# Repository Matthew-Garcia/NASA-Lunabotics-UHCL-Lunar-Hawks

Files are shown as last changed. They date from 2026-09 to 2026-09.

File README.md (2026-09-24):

> **New simulation review branch:** [Full rover CAD, Gazebo/RViz launch and KiCad Rev C](docs/SIMULATION_REVIEW.md). Reference-derived geometry; runtime and electrical review remain pending.

<p align="center">UHCL Lunar Hawks team logo</p>

# NASA Lunabotics · UHCL Lunar Hawks

### Proof-of-concept lunar excavation rover
Embedded systems · ROS 2 · micro-ROS · OpenCV · LiDAR · Gazebo · Hardware integration

A University of Houston–Clear Lake student and research rover project for lunar-regolith excavation, collection, transportation, and disposal.

This repository brings together the Lunar Hawks rover's ESP32 firmware, NVIDIA Jetson ROS 2 software, micro-ROS communication, mechanical models, electrical documentation, Gazebo simulation assets, and ongoing autonomous-navigation development.

**Status: prototype / research.** Physical rover subsystems have been demonstrated, while the newly added autonomous mission software and simulation environment remain development implementations requiring integration and validation on the physical rover.

This is a team-member-maintained academic/research repository and is **not a NASA-owned or NASA-endorsed software release**.

[ROS 2](ros2_ws/README.md) ·
[micro-ROS](firmware/micro_ros/README.md) ·
[MicroPython](firmware/micropython/README.md) ·
[Autonomy](ros2_ws/src/lunabotics_autonomy/) ·
[Gazebo Simulation](simulation/) ·
[CAD](cad/) ·
[Control PCB](hardware/rover_control_pcb/README.md) ·
[Research](docs/publication/README.md) ·
[Testing](docs/testing/README.md)

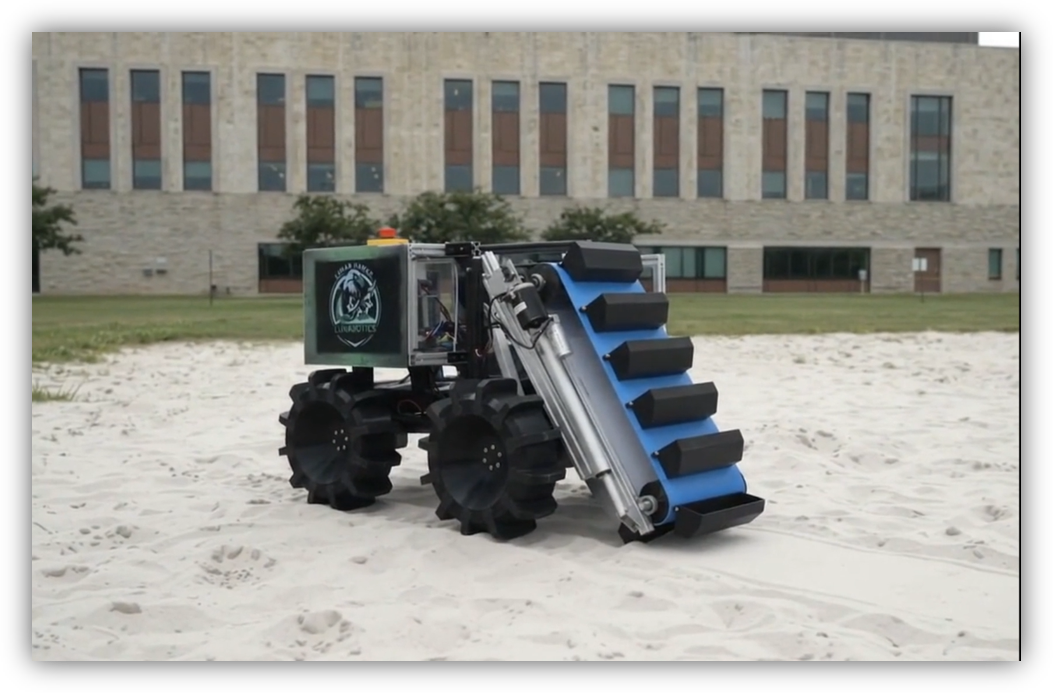
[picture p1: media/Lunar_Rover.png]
UHCL Lunar Hawks physical rover prototype


---

## Project objectives

The Lunar Hawks rover is being developed as a proof-of-concept robotic platform for lunar excavation research.

The overall mission architecture is intended to support:

1. Entering a simulated or competition excavation environment.
2. Navigating using LiDAR and camera sensing.
3. Identifying traversable regolith terrain.
4. Operating the front bucket-ladder / conveyor excavation mechanism.
5. Transporting collected material.
6. Detecting the disposal area using computer vision.
7. Identifying the four goal-post features surrounding the disposal zone.
8. Aligning the rover with the goal.
9. Activating the disposal bucket.
10. Returning to navigation or excavation behavior.

The current autonomous software is a development baseline rather than a fully validated competition autonomy stack.

---

## Demonstration and evidence

[Watch the archived Gazebo simulation clip](media/Gazebo_Sim.mp4) ·
[Original software documentation](docs/legacy/UHCL_NASA_Lunabotics_Rover_Software_Documentation.pdf)

The physical rover project has demonstrated subsystem functionality including:

- Forward and reverse mobility
- Differential-drive turning
- Wireless teleoperation
- Conveyor / bucket-ladder operation
- Material transportation
- Disposal-bucket actuation
- Jetson-to-ESP32 communication
- micro-ROS integration
- LiDAR integration
- Camera integration

These historical demonstrations do **not** automatically validate the newly added autonomy, Gazebo, CAD, or electrical-development files.

Physical test videos, measured results, software revisions, and dated validation records should continue to be added to the [testing evidence register](docs/testing/README.md).

| Area | Included here | Verification status |
| --- | --- | --- |
| ESP32 micro-ROS | Original C firmware and integration metadata | Preserved project source; hardware revalidation recommended |
| Jetson ROS 2 | Teleoperation and controller software | Existing architecture; environment validation ongoing |
| OpenCV vision | Goal-post and regolith detection nodes | Development baseline; physical threshold tuning required |
| LiDAR autonomy | Front-obstacle safety node | Implemented baseline; rover testing required |
| Mission control | Autonomous excavation/transport/disposal state machine | Implemented baseline; not yet a demonstrated full autonomous mission |
| Gazebo simulation | Lunabotics arena world and rover model | Source added; integrated launch and runtime validation still required |
| Mechanical CAD | Original rover STLs plus autonomy-development CAD | New models are reference/development geometry |
| Rover wheel | 304.8 mm × 100 mm conceptual wheel with 12 grousers | Parametric recreation; hub dimensions must be verified before fabrication |
| Rover control PCB | Routed 4-layer KiCad 9 ESP32/CAN design with USB programming and safety/inhibit logic | ERC/DRC clean; pending fabrication and bring-up |
| Electrical Rev B | Architecture recommendations and schematic review | Engineering-development documentation |
| Research | Manuscript/project documentation | Research publication workflow ongoing |

---

# System architecture

```mermaid
flowchart TD

    Controller["Xbox / Game Controller"] --> Jetson["NVIDIA Jetson Orin NX"]

    Camera["RGB / Depth Camera"] --> Jetson
    Lidar["RPLIDAR"] --> Jetson

    Jetson --> ROS["ROS 2 Humble"]

    ROS --> Teleop["Teleoperation"]
    ROS --> Vision["OpenCV Perception"]
    ROS --> Navigation["Navigation / Mission Logic"]
    ROS --> Safety["LiDAR Safety"]

    Vision --> Mission["Autonomous Mission Manager"]
    Navigation --> Mission
    Safety --> Mission

    Mission --> CMD["/cmd_vel"]
    Teleop --> CMD

    CMD --> Agent["micro-ROS Agent"]

    Agent -->|"UART 115200"| ESP32["ESP32"]

    ESP32 --> WheelDrivers["Wheel Motor Controllers"]
    ESP32 --> Excavator["Excavation Actuators"]
    ESP32 --> Dump["Disposal Bucket Actuators"]

    WheelDrivers --> Wheels["Four Drive Motors"]
    Excavator --> Conveyor["Bucket-Ladder / Conveyor"]
    Dump --> Bucket["Regolith Disposal Bucket"]
```

The architecture separates high-level robotics computation from low-level actuator control.

### NVIDIA Jetson

The Jetson is responsible for higher-level robotics functions such as:

- ROS 2
- Computer vision
- LiDAR processing
- Mapping and localization
- Navigation
- Mission coordination
- Future autonomous excavation behavior

### ESP32

The ESP32 provides hardware-facing embedded control including:

- Motor command generation
- PWM
- Direction control
- Actuator control
- micro-ROS communication
- Hardware safety behavior

The deployed ESP32-WROOM implementation and any future ESP32-S3 control PCB should **not be assumed to be pin-compatible or firmware-compatible without verification**.

---

# Autonomous mission development

The repository now contains an experimental ROS 2 autonomy package:

```text
ros2_ws/src/lunabotics_autonomy/
```

Major nodes include:

### Goal-post detector

```text
goal_post_detector.py
```

Uses OpenCV image processing to locate vertical goal-post candidates from the camera stream.

Publishes goal information that can be used to center the rover between the visible posts.

Development topics include:

```text
/vision/goal_posts/target
/vision/goal_posts/count
/vision/goal_posts/debug
```

The current detector uses configurable image-processing thresholds intended primarily as a simulation and development baseline.

---

### Regolith detector

```text
regolith_detector.py
```

Provides a preliminary OpenCV terrain-classification method for identifying regolith-like regions.

The current implementation is intentionally simple and should eventually be replaced or supplemented with perception trained and tested using representative lunar-regolith imagery.

---

### LiDAR safety

```text
lidar_safety.py
```

Processes `/scan` data and monitors the forward sector of the rover.

It can issue an obstacle-stop condition if an object is detected inside the configured safety distance.

Example topics:

```text
/safety/obstacle_stop
/safety/front_clearance
```

---

### Mission manager

```text
mission_manager.py
```

Implements a development state machine:

```text
ENTER
  ↓
SEARCH_REGOLITH
  ↓
EXCAVATE
  ↓
SEARCH_GOAL
  ↓
ALIGN_GOAL
  ↓
DUMP
  ↓
DONE
```

The mission manager can command:

```text
/cmd_vel
/excavator/enable
/bucket/dump
```

These outputs are intended to eventually interface with the existing ESP32 / micro-ROS hardware layer.

---

# Gazebo simulation

A Lunabotics-inspired Gazebo development environment is included under:

```text
simulation/worlds/
```

Current world:

```text
lunabotics_arena.world
```

The environment contains:

- Excavation terrain
- Arena boundaries
- Disposal region
- Four visual goal posts
- A simplified mission layout

The environment is a **development approximation**, not a claim of exact NASA competition-field dimensions.

A simplified rover model is also included:

```text
ros2_ws/src/lunabotics_description/urdf/lunabotics_rover.urdf.xacro
```

It represents:

- Four-wheel differential drive
- Rover chassis
- Front excavation conveyor
- Rear disposal bucket
- LiDAR
- RGB camera

An integrated Gazebo spawn/bringup launch file is still planned.

<p align="center">
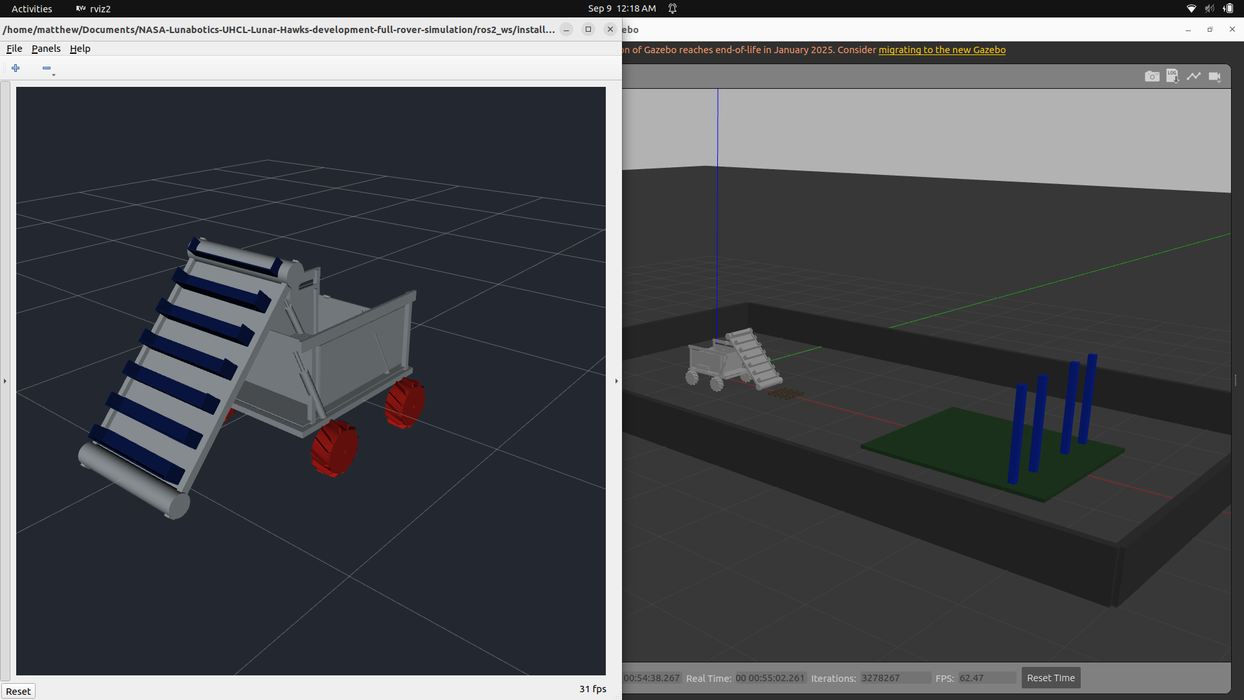
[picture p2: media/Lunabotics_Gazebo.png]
UHCL Lunar Hawks rover in Gazebo
  
</p>

*Lunar Hawks rover simulation with grouser wheels, a scoop conveyor excavator, and an actuator-driven disposal bucket. Full autonomous excavation and disposal remain under development.*

---

# Computer vision

The autonomy software uses OpenCV as a development perception layer.

Current objectives include:

```text
Camera
   ↓
OpenCV
   ↓
Goal-post detection
   ↓
Four-post confirmation
   ↓
Goal-center calculation
   ↓
Rover alignment
   ↓
Dump sequence
```

Future work may combine camera information with LiDAR geometry for more robust goal detection and navigation.

---

# LiDAR navigation

LiDAR provides the geometric sensing layer for autonomous rover development.

Planned progression:

```text
LiDAR
  ↓
Obstacle detection
  ↓
Localization
  ↓
Mapping
  ↓
Nav2 costmaps
  ↓
Waypoint navigation
  ↓
Mission navigation
```

Future integration is expected to include ROS 2 Nav2 and/or SLAM Toolbox.

---

# Mechanical development

The repository includes both preserved project CAD and new development geometry.

```text
cad/
```

The original supplied meshes remain directly in `cad/`. Generated geometry is separated by purpose:

```text
cad/
├── original supplied STL files
├── full_rover/
│   ├── chassis, bucket and excavator parts
│   ├── ESP32 and Jetson enclosures
│   └── 248 mm and 300 mm wheel variants
└── autonomy_rover/
    ├── goal_post.scad / .stl
    ├── grouser_wheel_12_short.scad / .stl
    └── rover_chassis_simplified.scad / .stl
```

The full-rover wheel set and printable cover variants are documented in [`cad/full_rover/WHEEL.md`](cad/full_rover/WHEEL.md).

## Grouser wheel

The development wheel is based on documented rover dimensions:

- Diameter: **304.8 mm**
- Width: **100 mm**
- Grousers: **12**
- Equal angular spacing: **30°**

The grouser projection in this development model was shortened relative to the initial generated geometry.

The wheel STL is **not fabrication-authoritative**. Hub diameter, shaft bore, bolt-circle dimensions, materials, tolerances, and drivetrain interfaces must be verified against the physical rover.

---

# Electrical architecture

The rover uses separated high-current motor and computing power domains.

```mermaid
flowchart TD

    BAT24["24 V Battery"] --> Fuse["Main Fuse"]
    Fuse --> Estop["Latching E-Stop / Contactor"]
    Estop --> Dist["Fused 24 V Distribution"]

    Dist --> FL["Front Left Motor Controller"]
    Dist --> FR["Front Right Motor Controller"]
    Dist --> RL["Rear Left Motor Controller"]
    Dist --> RR["Rear Right Motor Controller"]
    Dist --> EX["Excavator / Conveyor"]
    Dist --> ACT["Linear Actuators"]

    VMOUNT["V-Mount Compute Battery"] --> JetsonFuse["Compute Fuse / Protection"]
    JetsonFuse --> Jetson["Jetson Orin NX"]

    Logic["Regulated Logic Rail"] --> ESP32["ESP32"]
    Logic --> Sensors["Low-Voltage Sensors"]

    Jetson <-->|"UART / micro-ROS"| ESP32
```

Rev-B design recommendations are located in:

```text
docs/electrical/rev_b/
```

They include:

- Main battery protection
- Branch fusing
- Emergency-stop architecture
- Transient suppression
- Power-domain separation
- Logic-rail decoupling
- UART signal protection
- Test points
- Current-monitoring recommendations
- Motor-controller schematic review

One important design-review item is ensuring that schematic symbols and labels accurately represent the physical motor controllers being used.

---

# Start with software-only checks

Clone the repository:

```bash
git clone https://github.com/Matthew-Garcia/NASA-Lunabotics-UHCL-Lunar-Hawks.git

cd NASA-Lunabotics-UHCL-Lunar-Hawks
```

Run MicroPython protocol tests:

```bash
python3 firmware/micropython/test.py
```

Run repository tests:

```bash
python3 -m unittest discover -s tests -v
```

For ROS 2 setup, see:

[ROS 2 workspace instructions](ros2_ws/README.md)

For micro-ROS integration:

[micro-ROS notes](firmware/micro_ros/README.md)

Before powering physical motors or actuators:

[Electrical safety checklist](docs/electrical/SAFETY.md)

---

# Repository map

| Path | Purpose |
| --- | --- |
| `firmware/micro_ros/` | ESP32 C / micro-ROS firmware |
| `firmware/micropython/` | MicroPython communication prototype |
| `ros2_ws/src/lunabotics_teleop/` | ROS 2 controller and teleoperation package |
| `ros2_ws/src/lunabotics_autonomy/` | OpenCV, LiDAR, and autonomous mission development |
| `ros2_ws/src/lunabotics_description/` | Rover URDF/Xacro description |
| `simulation/worlds/` | Gazebo Lunabotics arena |
| `hardware/rover_control_pcb/` | Proposed rover-control/interface PCB |
| `cad/` | Mechanical models and original STL files |
| `cad/full_rover/` | Full rover reconstruction, excavator, bucket, enclosures and wheel variants |
| `cad/autonomy_rover/` | Earlier simplified autonomy-development CAD and goal-post geometry |
| `docs/architecture/` | Interfaces, command semantics, and system architecture |
| `docs/electrical/` | Electrical safety and architecture documentation |
| `docs/electrical/rev_b/` | Rev-B electrical recommendations and schematic review |
| `docs/testing/` | Evidence register and validation planning |
| `docs/publication/` | Research publication status |
| `docs/legacy/` | Original software documentation |
| `media/` | Rover images, team media, and Gazebo video |
| `tests/` | Host-side software tests |

---

# Development roadmap

- [x] Integrate Jetson and ESP32 architecture.
- [x] Establish ROS 2 teleoperation.
- [x] Establish micro-ROS communication.
- [x] Integrate LiDAR hardware.
- [x] Integrate camera hardware.
- [x] Demonstrate rover mobility.
- [x] Demonstrate excavation conveyor operation.
- [x] Demonstrate disposal-bucket actuation.
- [x] Add OpenCV goal-post detection baseline.
- [x] Add regolith-vision development node.
- [x] Add LiDAR obstacle-safety node.
- [x] Add autonomous mission state-machine baseline.
- [x] Add Gazebo Lunabotics arena source.
- [x] Add simplified rover URDF/Xacro.
- [x] Add 12-grouser wheel development CAD.
- [x] Add Rev-B electrical architecture review.
- [ ] Complete ROS package for rover description and Gazebo spawning.
- [ ] Add combined simulation launch file.
- [ ] Integrate ROS 2 Nav2.
- [ ] Integrate SLAM / localization.
- [ ] Fuse camera and LiDAR perception.
- [ ] Validate four-post detection using representative physical targets.
- [ ] Validate autonomous navigation on the physical rover.
- [ ] Integrate autonomous excavation control with ESP32 firmware.
- [ ] Implement mission recovery and watchdog behavior.
- [ ] Record quantitative excavation and navigation results.
- [ ] Complete and independently review production PCB schematic/layout.
- [ ] Demonstrate a complete autonomous excavation → transport → disposal mission.

---

# Research

**Matthew Garcia**  
Repository maintainer · Robotics systems integration · Embedded systems · ROS 2 / autonomy contributor · Co-Author

**Dr. Luong Nguyen, Ph.D.**  
Research adviser · Lead-Author

Credit also belongs to the **University of Houston–Clear Lake Lunar Hawks team** and the students who designed, built, tested, and improved the rover platform.

Research project:

*Design and Implementation of a Proof-of-Concept Excavating Rover Platform for Lunar Regolith Collection and Transportation*

The project has been accepted for presentation at **ISMCR 2026 — International Symposium on Measurement and Control in Robotics**.

Research documentation and publication status are maintained under:

[Read the author manuscript (Word)](docs/publication/manuscript/Nguyen_Garcia_ISMCR2026_Final_Revision.docx) · [Publication status](docs/publication/README.md)

---

## Links

[Matthew Garcia Portfolio](https://matthew-garcia-portfolio.vercel.app/) ·
[LinkedIn](https://www.linkedin.com/in/matthew-garcia-165634195/) ·
[Original UHCL Lunar Hawks Repository](https://github.com/Matthew-Garcia/uhcl-lunar-hawks-lunabotics)

---

# Safety

This repository contains software and design material capable of controlling motors and electromechanical actuators.

Do not connect development software directly to powered hardware without verifying:

- Emergency stop functionality
- Motor-controller pin assignments
- PWM ranges
- Direction logic
- Current limits
- Fuse ratings
- Mechanical clearance
- Command timeout behavior
- Communication-loss behavior

See:

[Electrical Safety](docs/electrical/SAFETY.md)

---

# License and provenance

The original MIT license is retained.

See [NOTICE](NOTICE.md) for source revision, provenance, and rights information.

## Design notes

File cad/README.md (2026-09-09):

# Mechanical CAD and meshes

The CAD tree separates preserved project files from generated development geometry:

- The five STL files directly in `cad/` are the original supplied actuator, sprocket, bucket, door-frame and hatch meshes. Their filenames remain unchanged for traceability.
- [`full_rover/`](full_rover/) contains the reference-derived complete rover reconstruction: chassis, excavator, bucket, actuators, electronics enclosures and wheel variants.
- [`autonomy_rover/`](autonomy_rover/) contains the earlier simplified autonomy-development chassis, goal-post and 12-grouser wheel models.

See [`full_rover/WHEEL.md`](full_rover/WHEEL.md) for the 248 mm Bambu-compatible wheel and 300 mm laboratory wheel variants.

Native STEP/SolidWorks sources for the complete rover were not supplied. Before printing or manufacturing, confirm units, scale, hub and fastener interfaces, tolerances, materials, load suitability, authorship and third-party licensing. Generated geometry is reference/development CAD, not a fabrication-authoritative release.

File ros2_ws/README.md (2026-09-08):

# ROS 2 Humble teleoperation

The actual package uses joy + joy_teleop, not teleop_twist_joy. The hardcoded old home-directory path is replaced by package-share lookup. Controller mappings are retained but require physical controller verification.

## Build on Ubuntu 22.04 with ROS 2 Humble installed

From the repository root, with colcon and initialized rosdep available:

~~~bash
source /opt/ros/humble/setup.bash
cd ros2_ws
rosdep install --from-paths src --ignore-src -r -y
colcon build --symlink-install
source install/setup.bash
ros2 launch lunabotics_teleop rover_joystick_teleop.launch.py
~~~

These commands target the ROS environment, which was unavailable during migration.

The default command topic is /lunabotics/cmd_vel_preview, not the original motor-facing /cmd_vel. Do not start a motor-facing agent for this check. In a second sourced terminal inspect:

~~~bash
ros2 topic echo /joy
ros2 topic echo /lunabotics/cmd_vel_preview
~~~

Button 5 is the configured deadman; axes 1/3 drive and 6/7 actuator groups. These are indices, not a verified mapping for every controller. The YAML maps angular.y but this firmware does not consume it.

Only after safety review and target tests can a reviewed deployment override command_topic:=/cmd_vel. This does not replace a hardware emergency stop or MCU watchdog. No Nav2, sensors, robot model, or autonomous control are included.

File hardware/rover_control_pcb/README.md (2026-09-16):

# NASA Lunabotics — UHCL Lunar Hawks Low-Level Embedded Control & I/O PCB

**Native KiCad 9.0 rover-control hardware design** for the University of Houston–Clear Lake Lunar Hawks Lunabotics rover.

This board is the rover's **low-level embedded control and I/O PCB**. The NVIDIA Jetson Orin NX remains the high-level ROS 2/autonomy computer, while this PCB handles the hardware-facing embedded layer: ESP32 control, CAN communication, programming/service I/O, safety/inhibit logic, and command interfaces to external wheel and mechanism drivers.

> **Engineering draft — not released for fabrication or powered operation.** ERC/DRC results establish design-file consistency, not electrical, thermal, RF, EMC, harness, or safety qualification.

## Designed in KiCad 9.0

The controller is designed and maintained **natively in KiCad 9.0**. The current design snapshot was validated with the KiCad 9 toolchain.

The KiCad project includes the project file, hierarchical schematic sheets, routed PCB layout, local symbol resources, 3D-model support, board artwork, BOM/component records, placement data, layout notes, and electrical validation reports.

## Rover control hierarchy

```text
NVIDIA Jetson Orin NX
High-level ROS 2 / autonomy / perception / planning
                 |
                 | CAN / system interface
                 v
LOW-LEVEL EMBEDDED CONTROL & I/O PCB
ESP32 / safety logic / command generation / hardware I/O
                 |
                 v
External motor drivers / actuators / excavation / disposal
```

The board silkscreen identifies the design as:

- **NASA LUNABOTICS — UHCL LUNAR HAWKS**
- **LOW-LEVEL EMBEDDED CONTROL & I/O PCB**
- **CONTROL SIGNALS ONLY — NO MOTOR POWER**

## Current board

- 160 × 100 mm working outline
- four copper layers
- blue solder mask / white silkscreen configuration
- ESP32-WROOM-32E-N4 embedded controller module
- USB-C programming/service interface
- Classical CAN interface with two parallel connectors and selectable 120 Ω termination
- four external BLDC wheel-driver command interfaces
- external linear-actuator / excavation / deployment / disposal command interfaces
- protected controller power conversion to 5 V and 3.3 V rails
- watchdog, re-arm, command-enable, and inhibit logic
- provisional wheel-stop request interfaces
- system/status indicators and service headers
- four mounting holes and Lunar Hawks board artwork
- **motor-current paths remain external to the PCB**

## Architecture notes

**Embedded controller:** the ESP32 provides the low-level hardware-control layer. Manual BOOT/reset support and the USB programming path are integrated on the board.

**CAN:** the controller-side CAN node includes the transceiver, protection, parallel bus connectors, and selectable termination. The Jetson requires its own appropriate CAN transceiver/adapter; logic-level CAN signals are not connected directly to CAN_H/CAN_L.

**Driver interfaces:** motor power is intentionally external. This PCB supplies command/control interfaces to the external wheel and rover-mechanism driver hardware.

**Safety/inhibit layer:** low-voltage interlock, watchdog, arm/re-arm, and command-inhibit functions are included. This PCB is not a safety-rated high-current disconnect; the rover's high-current emergency power interruption remains external.

## Board previews

### 3D board render

<p align="center">
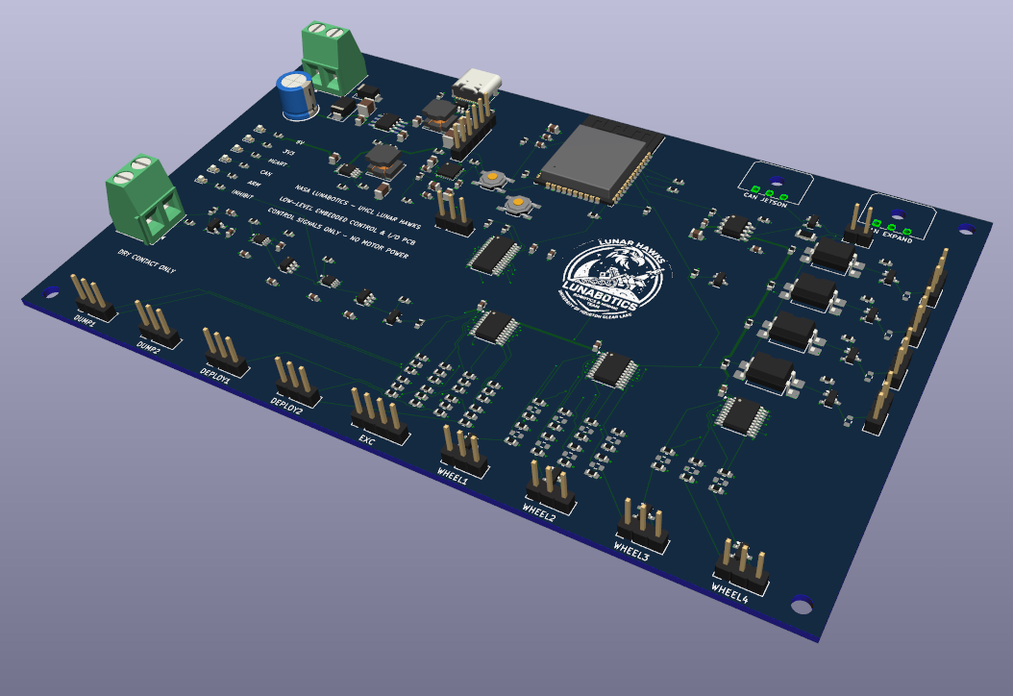
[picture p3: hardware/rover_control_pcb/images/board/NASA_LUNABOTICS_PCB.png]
NASA Lunabotics UHCL Lunar Hawks rover control PCB 3D render
  
</p>

### Top view

<p align="center">
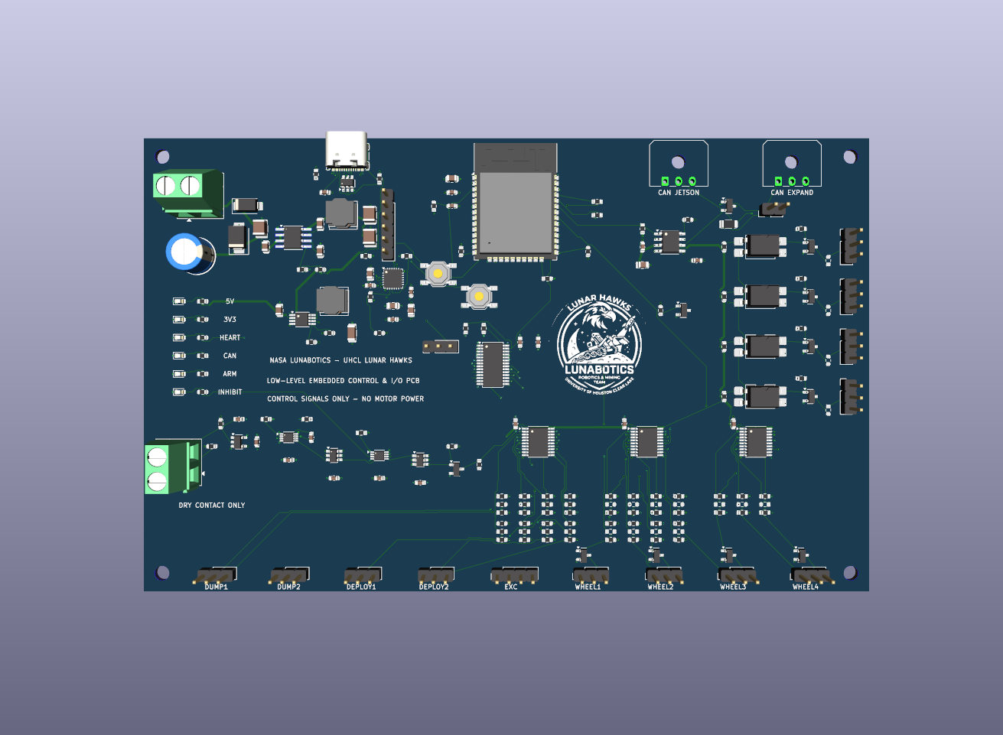
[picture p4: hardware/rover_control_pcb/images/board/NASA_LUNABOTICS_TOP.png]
NASA Lunabotics UHCL Lunar Hawks rover control PCB top view
  
</p>

### Front PCB layout

<p align="center">
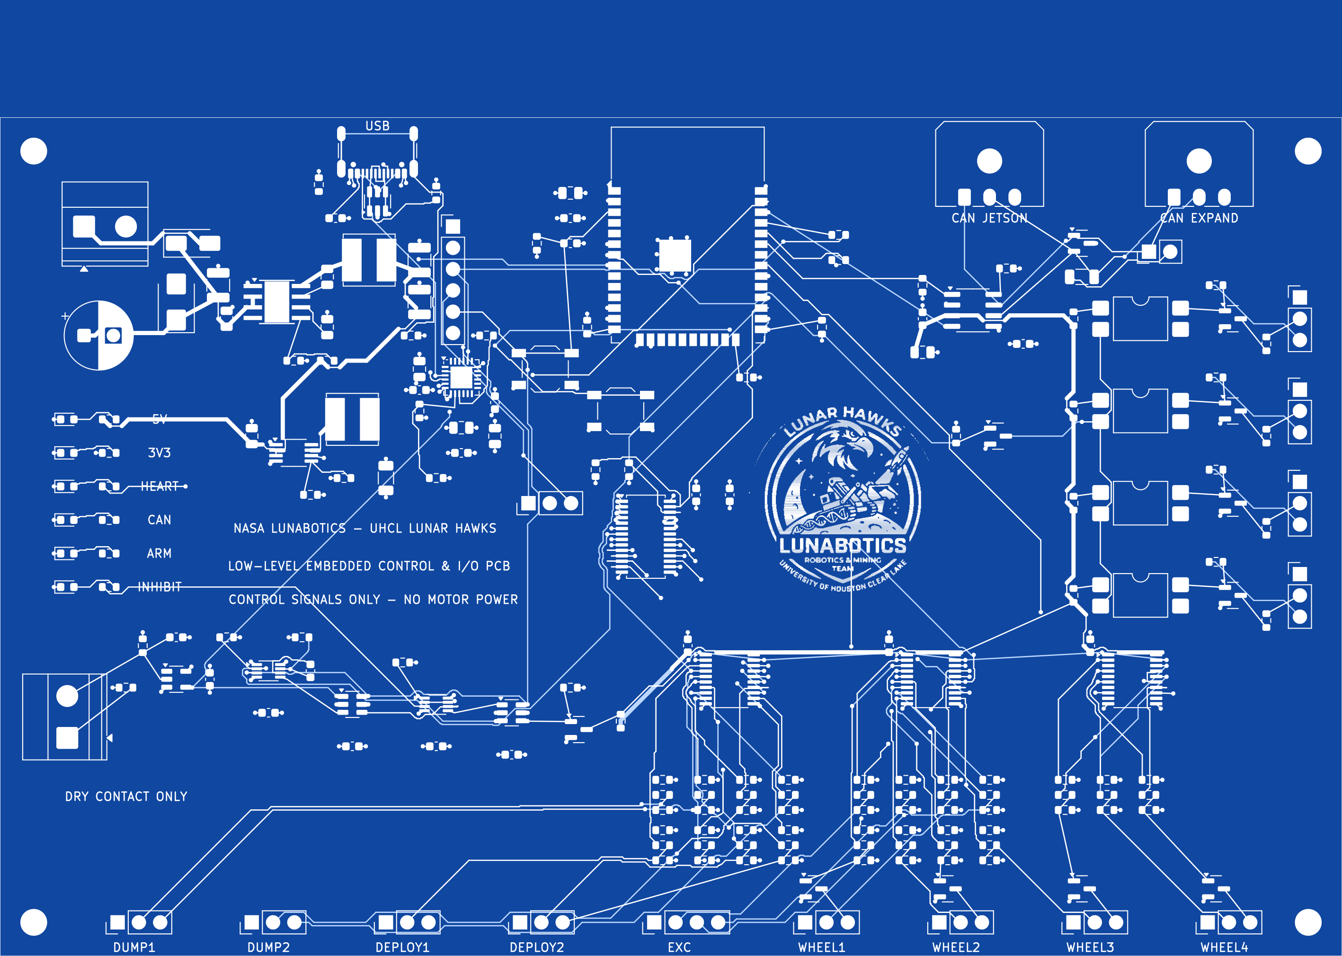
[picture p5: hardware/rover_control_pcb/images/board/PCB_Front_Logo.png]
NASA Lunabotics rover control PCB front layout and silkscreen
  
</p>

## Open the project

Open `Lunar_Hawks_Rover_Control.kicad_pro` in KiCad 9 with the standard KiCad symbol, footprint, and 3D-model libraries installed. Keep all child schematics, `Rover.kicad_sym`, `sym-lib-table`, and the `3dmodels` folder together. The corrected ESP32-WROOM-32E model is bundled and referenced using `${KIPRJMOD}`; other component models use standard KiCad libraries. The artwork is embedded in the PCB and the source image is preserved in `artwork/`.

## Current design

- 160 × 100 mm, four copper layers, blue solder mask and white silkscreen.
- Soldered ESP32-WROOM-32E-N4 module with integrated antenna; USB-C programming and Classical CAN interface.
- Interfaces for four external BLDC drivers, four external linear-actuator drivers, and one external excavator driver.
- Controller power conversion, status LEDs, watchdog/re-arm logic, and provisional wheel-stop interfaces.
- 201 schematic components: 186 populated and 15 DNP. Four mounting-hole footprints and two board-only logo footprints are additional, for 207 footprints total.
- 23 mm front logo and 48 mm rear logo. Their fine details require fabricator silkscreen capability review.
- Motor-current paths remain external to this controller PCB.

The preview uses white/light-blue trace colors for readability; these are display colors. The native PCB defines the manufacturing layers.

## Validation snapshot — September 16, 2026

KiCad 9.0.4 was run on this board with both logos, all-track-error reporting, schematic parity, and all severities including exclusions:

| Check | Result |
| --- | ---: |
| PCB DRC violations | 0 |
| Unconnected PCB items | 0 |
| Schematic/PCB parity issues | 0 |
| Schematic ERC errors | 0 |
| Schematic ERC warnings | 0 |

Reports: [PCB DRC](validation/PCB_Both_Logos_DRC.json), [schematic ERC](validation/Schematic_Both_Logos_ERC.rpt), and [layout status](validation/PCB_Layout_Status.json).

## BOM and design documentation

- [Grouped draft BOM](bom/BOM.md) and [individual component records](bom/BOM_Components.json). Exact ordering codes still marked TBD must be selected and verified before purchase.
- [Physical layout notes](docs/PCB_Layout_Notes.md), [power design](docs/Power_Design.md), [driver interfaces](docs/Driver_Interfaces.md), [interlock design](docs/Safety_And_Driver_Design.md), and [wheel-stop interfaces](docs/Wheel_Stop_Design.md).
- [Hardware requirements](docs/Hardware_Requirements.md) and [detailed design notes](docs/Design_Notes.md).
- `data/PCB_Placement.csv` is a draft position inventory of the 201 circuit components and four mounting holes; artwork is excluded. It is not a released assembly pick-and-place file.

## Remaining engineering review

Review power-converter current paths and thermal behavior, USB routing, ESP32 footprint and antenna clearance, exact component packages, connector pinouts/control levels, mounting dimensions, and the manufacturing stackup. Resolve the external E-stop DC interruption rating and J301 dry-contact permissive wiring; qualify DNP driver links. Sensor/end-limit circuits, paired-actuator synchronization, firmware, and hardware testing remain outstanding. The sensor sheet is a placeholder. No manufacturing Gerber/drill release is included.

## Rear PCB artwork

<p align="center">
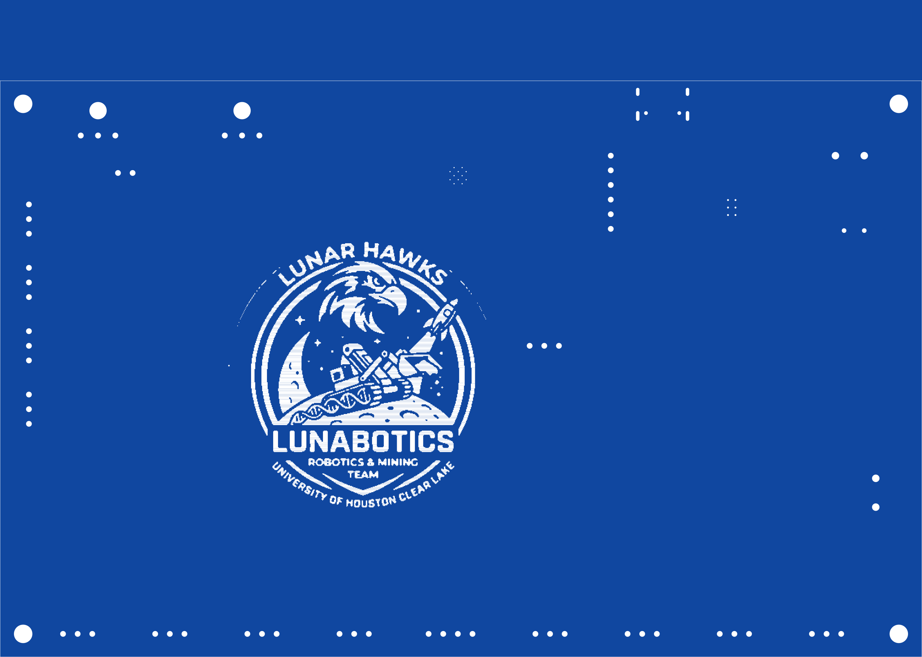
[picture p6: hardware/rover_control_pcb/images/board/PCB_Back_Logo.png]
NASA Lunabotics UHCL Lunar Hawks rear PCB artwork
  
</p>

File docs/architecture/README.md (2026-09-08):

# System and interface notes

The source implements ROS 2 joystick commands and an ESP32-WROOM micro-ROS subscriber. It is not a Nav2 or autonomous excavation implementation.

| Signal | Behavior in preserved app.c |
| --- | --- |
| Twist.linear.x | Forward/reverse drive input |
| Twist.angular.z | Turning input |
| Twist.linear.y | Bucket actuator group; thresholds ±0.5 |
| Twist.linear.z | Excavator actuator group; thresholds ±0.5 |
| Twist.angular.y | Mapped in controller YAML but NOT consumed by this C file |

Linear.y/z actuator use is a legacy custom convention, not standard spatial-velocity semantics. Do not connect navigation directly without an adapter and separate actuator interfaces.

Source constants: track-width parameter 0.465 m, linear/angular clamps ±1.0, velocity-to-duty gain 200, PWM 20 kHz with 8-bit duty. These are software settings, not measured maximum speed or independently confirmed dimensions. No encoder feedback is implemented in this file.

| Channel | PWM GPIO | Direction GPIO |
| --- | --- | --- |
| Front right | 32 | 33 |
| Back right | 12 | 13 |
| Front left | 25 | 26 |
| Back left | 27 | 14 |

Bucket group uses GPIO23/22; excavator group uses GPIO19/18. GPIO12 is a boot-strapping concern. These pins are WROOM-era code, not a pinout for the proposed S3 PCB. The source defines two actuator control groups, not four independent axes.

The owner reports 115200-baud Jetson/ESP32 serial operation; transport initialization and UART pins are not supplied by app.c. Confirm both in the original platform project. Sensor integration is reported for the platform, but no sensor drivers, calibration, SLAM configuration, URDF, or navigation nodes are included.

## Power boundaries

The owner describes a fused nominal-24 V motor domain and a separate V-mount-powered Jetson domain. Separate batteries alone do not establish galvanic isolation. Verify signal references, voltage levels, protection, and any intended isolation barriers before connecting UART. The proposed PCB is a signal/interface board, not a high-current motor-power board.

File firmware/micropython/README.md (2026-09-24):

# MicroPython: three-file dry-run prototype

**New examples, not recovered historical rover firmware. No GPIO/PWM output implementation is included.** micro-ROS and MicroPython are alternative MCU firmware images.

| File | Purpose |
| --- | --- |
| boot.py | Inert startup notice; no automatic Wi-Fi/server or GPIO |
| test.py | Portable logic self-test without networking or physical motion |
| main.py | Limited WebSocket server, validated normalized command mixer, dry-run timeout state |

## Host demo

~~~bash
python3 firmware/micropython/test.py
python3 firmware/micropython/main.py
~~~

Connect a WebSocket client to ws://127.0.0.1:8765/control and send:

~~~json
{"v":0.25,"w":0.0,"deadman":true}
~~~

Replies report dry_run, left, and right. Inputs are normalized [-1,1], NOT m/s, rad/s, or PWM duty. Send at about 10 Hz for a sustained demo. Deadman false clears the request; malformed commands/disconnect clear it; a 500 ms no-valid-command interval clears it via the watchdog. This is software-only state and is not a safety-rated stop.

## On an ESP32

Install the appropriate MicroPython image only after backing up existing firmware and disconnecting motor power. Copy these three files to the board. At the REPL, configure a private lab Wi-Fi connection manually (do not commit credentials), import main and asyncio, then explicitly run asyncio.run(main.serve(host="<board-private-IP>")). Target execution is not yet verified.

boot.py deliberately does not touch pins; it cannot guarantee safe physical output levels. Hardware inhibit must hold drivers disabled. A separate, reviewed motor adapter, hardware interlocks, pin mapping, output fault handling, and target tests are required before any physical control.

## Protocol limits and security

One active client. Only masked, unfragmented text frames of at most 125 bytes; close/ping/pong supported, no binary, compression, or extended-length frames. Full HTTP header capped at 2048 bytes and two seconds. Frame reads bounded to 500 ms. Not a general-purpose WebSocket stack. No authentication or TLS; localhost or isolated lab network only. Do not expose to the internet or attach actuator outputs.

API references: [MicroPython ESP32](https://docs.micropython.org/en/latest/esp32/quickref.html) and [asyncio](https://docs.micropython.org/en/latest/library/asyncio.html). These upstream pages describe the development branch; pin and test the deployed interpreter before relying on target compatibility.

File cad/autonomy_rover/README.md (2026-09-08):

# CAD notes

`grouser_wheel_12_short.scad` is the main requested wheel model. It preserves the documented **304.8 mm diameter, 100 mm width and 12 evenly spaced grousers**, while using a 22 mm radial grouser projection in the parametric source (half of the 44 mm baseline used in this generated model).

These files are simulation/reference geometry, not production-release mechanical drawings. The wheel should be dimension-checked against the rover's actual hub/bolt pattern before printing.

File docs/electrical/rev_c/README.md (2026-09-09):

# Rev C system wiring schematic

Open `Lunar_Hawks_RevC.kicad_sch` in KiCad 9. This is a new system-wiring draft, not a routed PCB or a completed component-level replacement for the uploaded schematic.

The four wheel controllers are explicit external **BLDC modules** with U/V/W phases. They no longer use an inappropriate DRV8871 IC symbol as a BLDC controller. Separate fused branches supply conveyor and actuator-driver modules. A hardware NC E-stop breaks the DC contactor coil circuit. A separate compute supply and isolated UART module avoid intentionally joining motor and computer grounds.

All module ports are logical interface names, **not physical connector pin numbers**. Every signal is wired to a named net; the exact module connections are also listed in `module_connections.json`.

Unresolved design inputs: exact BLDC controller model and input voltage thresholds, Jetson carrier and input rating, converter specifications, motor stall currents, fuse/wire/contactor ratings, actual ESP32 pin map, actuator limit switches and synchronization. Coil flyback suppression, transient/reverse-polarity protection and a hardware watchdog require component-level selection and wiring. Check that USB or chassis connections cannot bypass intended isolation.

Validation performed: S-expression parse and explicit module/net generation. KiCad 9.0.9 loaded/rendered this schematic and reported zero ERC errors and warnings in GitHub Actions run 34298704677. Electrical performance remains unverified. Do not manufacture from this draft.

## C.1 mechanism update

Bucket and lift channels represent two actuator pairs (four actuators total); the lift pair deploys the excavator. Conveyor motor control is separate. F23/U23/Y1 add a logical fused latch-solenoid branch and clamped low-side driver. J23/U24/J24 document door, latch and actuator endpoint feedback. U24 represents pending ESP32 GPIO assignments, not a second microcontroller. A solenoid release is an assumption until the actual electronic latch is identified; coil voltage, duty cycle, suppression and driver selection are not finalized. The top-hinged door has no powered door motor.

ERC checks logical module connectivity here. The generic passive module pins do not validate voltage compatibility, protection sizing, isolation hardware or physical connector assignments.

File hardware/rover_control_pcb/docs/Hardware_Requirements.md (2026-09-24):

# Confirmed rover hardware

This mapping reflects the user's latest correction and supersedes earlier driver assignments.

| Function | Quantity | Motor/load | External driver |
|---|---:|---|---|
| Wheel propulsion | 4 | BLDC wheel motors | 4 x ZS-X11H, one per motor |
| Dump bucket | 2 | 12 VDC linear actuators | 2 x DRV8871, one per actuator |
| Excavator deployment | 2 | 12 VDC linear actuators | 2 x DRV8871, one per actuator |
| Excavator motor | 1 | 12 VDC motor | 1 x RANSANX L298 module |

Total: nine motor/actuator loads and nine external driver modules.

- Low-level controller: ESP32-WROOM; exact module variant pending.
- High-level computer: NVIDIA Jetson Orin NX; carrier-board model pending.
- Wheel controller link supplied by user: https://www.amazon.com/BLDC-Three-Phase-Brushless-Controller-Function/dp/B0D97PN96D
- ZS-X11H and RANSANX L298 model names are user-confirmed. Exact module revisions, terminal pinouts and electrical specifications have not yet been independently verified.

## Retained architecture

Nominal 24/25.6 V control-power input, 5 V and 3.3 V logic rails, Jetson UART, CAN and independent hardware E-stop. High-current motor power remains off the control PCB. The source of the 12 V motor/actuator supply is still to be confirmed.

## Interface decisions pending

- Exact module pinouts and control-input electrical requirements for ZS-X11H, RANSANX L298 and DRV8871 boards.
- Excavator and linear-actuator running/startup/stall currents; module current limits and thermal capability.
- Wheel motor voltage/current and Hall-sensor connections.
- Stop/brake/inhibit behavior of each driver type for the hardware E-stop design.
- Jetson carrier-board model and UART interface voltage.
- Actuator feedback, end limits and paired-actuator synchronization requirements.

The KiCad design remains an architecture scaffold; no driver circuits or connector pinouts have been implemented.

Exact user-supplied module links and DRV8871 control research are recorded in Driver_Interfaces.md.

## Battery, distribution and CAN - latest user confirmation

Battery: Talentcell 25.6 V nominal, 6 Ah LiFePO4. Exact label/model and maximum charge/discharge specifications are still to be verified; LF8011 appears to match the description but is not user-confirmed. 6 Ah is capacity, not a 6 A discharge-current limit.

Existing distribution as described by user: battery -> DC current meter/sensing -> fuse box -> drivers and loads. Meter model, high-side/low-side shunt arrangement, upstream cable protection and any voltage conversion are unspecified. A meter and fuse box do not reduce the battery voltage to 12 V.

The 12 V actuator and excavator branches require a suitable external 12 V supply stage. No converter has yet been confirmed. Do not finalize driver power wiring from the stated chain. Treat approximately 29.2 V as a provisional full-charge design assumption for an 8-series-cell LiFePO4 pack, subject to exact battery label verification; this exceeds the excavator module's seller-stated 27 V maximum. Input component selection must also account for transients. Converter capacity and battery discharge capability must be checked against actual simultaneous motor currents before selection.

CAN is explicitly requested for BOTH Jetson-to-ESP32 communication and future expansion boards. Proposed topology: one shared Classical CAN bus connecting Jetson, controller PCB and expansion nodes. Provide a CAN transceiver at the ESP32 and two parallel bus connectors for cable continuation, with selectable 120-ohm termination on the controller board. These connectors are the same bus, not independent CAN controllers. Termination belongs at the two physical bus ends. Bitrate and cable topology remain to be finalized.

Jetson carrier-board identity is required to determine whether it already has a CAN transceiver or needs an external transceiver/adapter. Keep UART in the agreed architecture as an additional interface. Existing motor drivers retain their discrete control interfaces; adding CAN to the controller does not make the driver modules CAN devices. Hardware E-stop remains independent of successful CAN communication.

Primary references:
- https://docs.espressif.com/projects/esp-idf/en/stable/esp32/api-reference/peripherals/twai.html
- https://docs.nvidia.com/jetson/archives/r36.4.4/DeveloperGuide/HR/ControllerAreaNetworkCan.html

No CAN circuit or power-converter circuit has yet been implemented in the schematic.

## Confirmed external buck converter

User confirms use of DROK adjustable CC/CV buck converter, Amazon ASIN B078Q1624B:
https://www.amazon.com/dp/B078Q1624B

Manufacturer product specifications for the matching 5.3-32 V / 12 A module:
- Recommended input range: 5.3-32 V.
- Adjustable output: 1.2-32 V, with input at least 0.8 V above output.
- Long-term output current: 8 A; up to 12 A with enhanced cooling.
- Natural-cooling output power: 120 W, also subject to 8 A current limit; enhanced-cooling power up to 160 W.
- At a proposed 12 V setting, 8 A corresponds to 96 W shared by all attached loads. This is a specification-based budget, not verified installed performance.

The converter's existence is now confirmed, superseding earlier statements that no converter was identified. Its quantity, installed position relative to the fuse box, actual output setting, current-limit setting and supplied load branches remain unknown. Do not assume it powers every 12 V load or the Jetson. The nominal battery voltage lies within its input range; verify battery maximum and transient voltage against the 32 V recommended maximum. Motor startup/stall and simultaneous-load currents must fit the converter, battery and protection limits.

Manufacturer source:
https://www.droking.com/Adjustable-CC-CV-Buck-Converter-Power-Supply-Module-CC-CV-Buck-Converter-DC-5.3V-32V-24v-Step-Down-Voltage-Regulator-12A-160W-Adapter-Driver

## Confirmed 12 V branch topology

User clarified the order as fuse box -> buck converter -> driver, then confirmed FIVE buck converters. Interpreted allocation: one DROK per each of the four 12 V actuator/DRV8871 branches and one DROK for the 12 V excavator/RANSANX driver branch. This supersedes the earlier possibility of one shared converter.

Battery -> DC current meter/sensing -> fuse box -> individual DROK buck -> external driver -> load.

| Branch | Converter | Driver | Load |
|---|---|---|---|
| Dump 1 | DROK 1 | DRV8871 1 | 12 V linear actuator |
| Dump 2 | DROK 2 | DRV8871 2 | 12 V linear actuator |
| Excavator deployment 1 | DROK 3 | DRV8871 3 | 12 V linear actuator |
| Excavator deployment 2 | DROK 4 | DRV8871 4 | 12 V linear actuator |
| Excavator motor | DROK 5 | RANSANX module, one channel | 12 V excavator motor |

12 V is the required load supply target; actual converter settings have not been measured or confirmed. Converter limits apply per branch. The battery, current meter, shared wiring and fuse-box feed must support the combined input load. Five converters do not increase battery discharge capability. Individual load currents, fuse ratings and battery discharge rating remain open. Wheel-driver supply details and Jetson carrier/power details remain to be confirmed. No power circuitry has been implemented in KiCad yet.

## Confirmed wheel-driver supply

User confirms all four ZS-X11H wheel drivers receive power directly from the battery-fed fuse box, without buck converters. Each connects to its corresponding BLDC wheel motor. The four wheel-motor voltage/current ratings remain unconfirmed; the driver's voltage range alone does not establish motor compatibility.

Confirmed distribution:
- Talentcell 25.6 V nominal, 6 Ah LiFePO4 -> DC meter/sensing -> fuse box.
- Four wheel branches: fuse box -> ZS-X11H -> BLDC wheel motor.
- Four actuator branches: fuse box -> individual DROK buck (12 V target) -> DRV8871 -> actuator.
- One excavator branch: fuse box -> individual DROK buck (12 V target) -> RANSANX driver -> excavator motor.

This documents nine motor/actuator branches and five converters. Main fuse, branch fuse values, conductor sizes, current budget and E-stop power switching are not yet designed. Jetson and controller power branches remain to be established.

## Jetson carrier identified from underside photo

Photo clearly shows Seeed Studio reComputer J401 V1.0, with user-confirmed Jetson Orin NX 16 GB. This resolves earlier carrier identification questions. Do not substitute specifications for J401B, J401 Mini or J401 Robotics variants.

The board photo marks 9-19 V, 5 A MAX at the input. Seeed's J401 documentation confirms 9-19 V DC input; its datasheet lists an optional 12 V / 5 A supply with 5.5/2.5 mm barrel jack. Do not connect the nominal 25.6 V battery directly to this jack. Existing Jetson power source is still unknown; the five already-confirmed DROK converters are allocated to motor/actuator loads, not the Jetson.

The photo shows a header labeled 3V3, GND, CAN_RX, CAN_TX. These are logic-side CAN signals, not CAN_H/CAN_L. Seeed's J401 interface documentation states an external CAN transceiver is required. Plan a Jetson-side transceiver close to the carrier header and an ESP32-side transceiver on the control PCB, connected via the shared differential CAN bus with expansion nodes. Exact connector orientation, pin numbers and transceiver implementation remain to be verified before cable construction. Use Classical CAN frames for compatibility with ESP32-WROOM.

Sources:
- User's underside photograph (board model and power/header markings).
- https://wiki.seeedstudio.com/J401_carrierboard_Hardware_Interfaces_Usage/
- https://files.seeedstudio.com/wiki/reComputer-J4012/reComputer-J401-datasheet.pdf

## Jetson separate V-mount battery supply

User reports Jetson powered from a separate V-mount battery through D-Tap. Supplied ASIN B0CJ8Z28CS currently identifies NEEWER PS099E, 6800 mAh / 99 Wh / 14.54 V nominal. This resolves the previously unknown Jetson power source; it does not consume one of the five motor-branch DROK converters.

NEEWER distinguishes BP/D-Tap output (14.54 V nominal, 14 A max listed) from the regulated DC12V port (12 V, 3 A max). Therefore do not label the D-Tap connection as confirmed regulated 12 V. NEEWER lists 16.8 V D-Tap charging; approximately 16.8 V full-charge pack voltage is an inference consistent with that specification, not a measured cable output. Nominal and expected full-charge voltages lie within the J401 9-19 V input range. Actual D-Tap-to-barrel cable regulation, polarity, connector fit, current capability and voltage under load remain unverified.

Retain two separate positive power systems: Talentcell for motor/control distribution and V-mount for Jetson. Do not join positive outputs. Separate batteries alone do not provide galvanic isolation once UART/CAN reference wires or other cables join the systems. CAN isolation/reference and optional UART isolation must be designed consistently; do not claim electrical isolation solely from separate batteries.

Sources:
- https://www.amazon.com/dp/B0CJ8Z28CS
- https://eu.neewer.com/products/neewer-ps099e-6800mah-14-5v-99wh-v-mount-battery-66603180
- https://wiki.seeedstudio.com/J401_carrierboard_Hardware_Interfaces_Usage/

## Implementation update: onboard USB and controller CAN

The project now has 49 components across MCU, USB and CAN circuit sheets. This supersedes earlier statements that CAN/USB are entirely unimplemented. See README.md for the current implementation and validation status. The Jetson-side external CAN transceiver remains pending. The current controller CAN node is non-isolated and uses a signal-reference conductor; it is not claimed to isolate the two battery systems. CAN activity LED is on GPIO32, heartbeat on GPIO23. Hardware-enable and fault/E-stop LEDs remain pending with the safety/interface design. The regulator power sheet and motor interfaces remain unfinished.

## Power circuit stage - current status
Protected controller power is now implemented in 01_Power. The project has 69 physical components across four implemented sheets. A dedicated fusebox branch feeds reverse-polarity/surge protection, a 5 V LMR36510 and a 3.3 V TPS62160. The five external motor bucks remain unchanged. 29.2 V maximum pack voltage is an 8S design assumption pending label confirmation. See Power_Design.md and README.md for current validation and pending work. PCB placement/routing, safety, drivers and sensors remain incomplete.

## A3 driver/interlock stage - latest status
The project now has 171 schematic components across six implemented sheets, including 11 DNP links. Command interfaces for nine drivers and a hardware command interlock are drawn; sensors remain pending. This supersedes earlier scaffold-only statements. See Safety_And_Driver_Design.md for actual connector/GPIO assignments and limitations. Wheel/excavator outputs remain disconnected by DNP links until verified; external E-stop power switching is not designed yet. J301 is a voltage-free auxiliary-contact input, not a contactor coil output or 24 V input. PCB placement/routing remains undone.

## ZS-X11H diagram received
The user supplied a ZS-X11H V2 wiring diagram identifying a dedicated 2.5-5 V PWM input (50 Hz-20 kHz), external PWM jumper, Rotation/Stop switches to GND and Brake switch to driver 5 V. See Driver_Interfaces.md for interpretation and remaining uncertainties. Wheel DIR circuitry still requires switch-emulation revision/qualification; DNP links remain. No schematic changes in this evidence update. External E-stop hardware details remain pending.

## E-stop button identified from user link

User supplied Amazon ASIN B00NTT91Y0: BAOMAIN enclosed red mushroom E-stop station, advertised with 1 NO and 1 NC contact and 660 V / 10 A markings. This identifies the button station, not a separate motor-power relay/contactor.

Amazon currently describes press-to-stop / clockwise twist-to-reset. A similar BAOMAIN manufacturer page instead says momentary and specifies AC 660 V / 10 A. Exact equivalence is not established, so confirm that the installed button stays latched when pressed and requires deliberate reset. Do not infer a DC motor interruption rating from the generic voltage/current markings.

Proposed role: the normally closed contact participates in the external de-energize-to-stop control circuit, subject to verified DC control-load rating and final safety architecture. Do not route all rover motor current through this button based on the listing. A 1NO+1NC assembly does not provide two independent NC channels. Do not reuse the same NC terminals simultaneously for a powered coil circuit and PCB J301; J301 accepts a separate voltage-free permissive contact only.

The actual relay/contactor or safety relay, coil supply, load ratings and feedback/reset arrangement remain unknown. No contactor wiring or PCB changes were made based on this link. Needed clarification: whether a separate relay/contactor is already installed and its model, and confirmation of the physical button's latching action.

Sources:
- https://www.amazon.com/dp/B00NTT91Y0
- https://baomain.com/products/momentary-emergency-stop-switch (similar manufacturer product; exact match unconfirmed)

## Confirmed installed E-stop wiring - supersedes relay uncertainty

The user confirms that battery power passes directly through the E-stop switch. The DC meter has four terminals: two connect to the battery; of the remaining two, the positive feed goes through the switch to fusebox positive, and the negative feed goes directly to fusebox negative. Terminal functions here describe the user's wiring; the meter model, printed terminal numbers and internal shunt arrangement are not verified.

Functional topology:
Battery +/- -> DC meter battery-side connections.
DC meter load-side positive -> latching E-stop switch -> fusebox positive.
DC meter load-side negative -> fusebox negative.
Fusebox -> four wheel controllers directly, plus five buck/driver branches for four actuators and the excavator motor.

There is no separate relay/contactor in the reported installation. Pressing the E-stop opens the motor distribution feed; twisting restores that feed. This confirms maintained/latching behavior on the installed button despite inconsistent web descriptions. It does not establish motor stopping time or suitability of the switch for the DC interruption duty.

The switch carries the aggregate current of every load downstream of that fusebox, not just a control signal. Its exact DC make/break rating, motor startup/stall current, converter inrush and wiring protection must be checked before accepting this as the final power-cutoff design. The advertised generic 660 V / 10 A marking is not verification for this DC motor load. Main protection ahead of the switch/meter is not yet established by the described topology; do not infer its absence or presence.

The existing proposed controller logic feed comes from a dedicated branch of this same fusebox. Under this topology, pressing E-stop also removes controller PCB power; restoring it causes a cold start. The separate Jetson V-mount supply is unaffected by this switch as described. Keeping controller diagnostics alive would require an explicitly redesigned, separately protected upstream logic branch; that change has not been made.

PCB J301 remains an unpowered dry-contact permissive input; it must not connect to either battery-carrying switch terminal. No spare NC permissive contact or external auxiliary relay is established by this wiring. The advertised spare NO contact is not automatically a suitable closed-when-permitted contact for J301. J301 therefore remains an unresolved integration point, and the current draft stays inhibited without a valid permissive; do not bypass it silently.

No schematic connectivity or component-population changes were made in this evidence update. Next engineering work is to validate the direct-switch DC load rating and resolve the independent low-voltage permissive interface, then finish the wheel switch-emulation circuitry. Required motor/current and switch contact-block data remain pending.

## A4 wheel-direction switch revision - current implementation

Q401-Q404 (AO3400A, SOT-23) now emulate ground-switching of each ZS-X11H Rotation input. J406-J409 pin 3 connects to its MOSFET drain; pin 1 is the shared signal ground/source. Gate drive comes from the hardware-inhibited buffer through the existing 220 ohm DNP link and has a 10 kohm pulldown. These are non-isolated open-drain switches, not voltage sources or isolated relay contacts. No PCB 5 V pullup was added to Rotation.

Once the links are qualified and populated, command high closes the switch to ground; command low or hardware inhibit releases it. Open/released is a direction state, not a stop command. Determine actual wheel direction with the motor unloaded; change direction only after stopping. Verify the effects of simultaneous PWM inhibition and direction release before load testing. No behavior under loss of a ground wire is guaranteed.

The eleven wheel/excavator links remain DNP. The diagram supports this interface topology but does not establish Rotation voltage, pullup current, open-circuit state or transient levels. Validate these against the 30 V MOSFET rating with appropriate margin before use. Wheel PWM still uses the separate dedicated throttle input. STOP/BRAKE/SC and J301 low-voltage permissive integration remain unfinished.

175 schematic components now, including 11 DNP links. ERC: zero errors/warnings. Existing checks pass, plus four MOSFET gate/source/drain-to-header checks, confirmation of no direct power-rail tie on Rotation outputs, and corresponding footprint-pad checks. No physical validation or PCB routing has been completed.

The earlier build_driver_stage.py generator predates this revision and must not be rerun over the current files without porting the changes. The native KiCad files are the deliverable.

## Wheel motor identification supplied by user

User supplied STEPperONLINE 57BLR50-24-01-HG100 product link in the wheel-load discussion. Treat as the proposed common model for the four wheels, pending confirmation that all installed units match.
Manufacturer listing: 24 V, rated current 5.0 A +/-10%, rated power 84 W, geared speed 35 RPM +/-10%, 100:1 gearbox, rated output torque 14.95 Nm. Source: https://www.omc-stepperonline.com/24v-84w-35rpm-geared-brushless-dc-motor-100-1-high-precision-gearbox-57blr50-24-01-hg100

Four identical units sum to 20 A nominal listed motor rated current (18-22 A with the stated tolerance). This is a preliminary motor-rating total, not a verified battery-side demand or startup/stall limit: the listing does not define its current measurement sufficiently for that conclusion, and PWM/controller operation affects DC-bus current. Actuator, excavation, converter and logic loads remain additional. Do not size the contactor, fuse or battery/BMS from this sum alone. Do not infer electrical input current from 84 W / 24 V in place of the listed current.

The earlier '6A' figure remains ambiguous; it has not been accepted as total rover current or a verified DC switch rating. The cited 6 A resistive / 2 A inductive switch ratings lack manufacturer verification. Installed BAOMAIN direct switching remains unqualified. No schematic changes were made by this motor-identification update.

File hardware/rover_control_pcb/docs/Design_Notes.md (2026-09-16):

# Lunar Hawks Rover Control - KiCad 9 physical PCB draft

Open Lunar_Hawks_Rover_Control.kicad_pro. Reload from disk if KiCad was already open; avoid saving a stale editor copy over external edits.

## Physical PCB draft

Open Lunar_Hawks_Rover_Control.kicad_pcb for the placed and routed layout. PCB_Front_Logo.png shows the board. PCB_Both_Logos_DRC.json and PCB_Layout_Status.json list remaining issues; do not infer PCB readiness from the schematic ERC result. See PCB_Layout_Notes.md for layer use and release limitations.

## Implemented

201 components across seven circuit sheets (including 15 DNP signal links):

| Sheet | Contents |
|---|---|
| 01_Power | Fused-branch input; reverse-polarity diode; SMBJ33A surge suppressor; LMR36510 5 V buck; TPS62160 3.3 V buck |
| 02_MCU_Comms | Soldered ESP32-WROOM-32E-N4; reset and BOOT buttons; reset timing; bypass capacitors; GPIO2/GPIO12 strap resistors; UART service header; 5 V, 3.3 V and heartbeat LEDs |
| 03_Safety | Dry-contact permissive input; hardware watchdog; re-arm latch; direct arm gating; command-enable and inhibited LEDs |
| 04_Drivers | PCA9685 command expansion; 19 buffered signals for nine external drivers; prototype headers; wheel/excavator links DNP pending verification |
| 06_USB_Programming | USB-C receptacle; separate CC pulldowns; USBLC6 data protection; CP2102N-A02-GQFN24; VBUS divider; bypass capacitors; USB/service UART selection jumper |
| 08_Wheel_Stop | Four driver-powered default Stop requests; hardware-enable release; four DNP qualification links |
| 07_CAN_Bus | TCAN1042HGVDRQ1 transceiver; NUP2105L protection; two parallel CAN connectors; selectable 120-ohm termination; firmware-driven CAN activity LED |

The sensors sheet remains a placeholder. External E-stop power cutoff, wheel STOP qualification, BRAKE/SC, excavator signal-power wiring and final harness interfaces are not completed. The PCB now has 201 placed schematic components, four mounting holes, reference planes and draft routing on a 160 x 100 mm four-layer outline. See PCB_Layout_Notes.md and PCB_Layout_Status.json for the current PCB check results. No fabrication release has been made.

## Programming operation

USB does not supply the controller's power rails. Power the board's logic supplies before programming. CP2102N is supplied from board 3.3 V, with its regulator bypassed and USB VBUS used only for sensing/protection. Set its USB configuration descriptor to self-powered during bring-up.

JP601: one shunt on pins 1-2 selects onboard USB TX; pins 2-3 select the external service UART. Never bridge both positions. Manual download uses BOOT held low while resetting the ESP32, then release BOOT after entering download mode. Automatic RTS/DTR reset circuitry is not implemented. Service-header pin 2 is 3.3 V reference, not a second power input. External service signals must be 3.3 V and must not back-power an unpowered controller.

## CAN operation and integration

Provisional MCU allocation: GPIO21 -> CAN TX; GPIO22 <- CAN RX; GPIO32 -> CAN activity LED; GPIO23 -> heartbeat. Driver GPIOs are now assigned as detailed in Safety_And_Driver_Design.md; sensor allocation is pending. CAN activity requires firmware to stretch successful TX/RX events into visible LED pulses.

Initial bus target is Classical CAN at 500 kbit/s, subject to cable validation. J701 and J702 share the same CAN bus: pin 1 CAN_H, pin 2 CAN_L, pin 3 signal GND. The draft uses Molex Micro-Fit 3.0 43650-0300 headers; harness housing/terminal selection remains pending. JP701 enables this board's 120-ohm termination only when installed at a physical bus end. Use two terminations across the whole bus, not one on every node.

The Jetson J401 requires its own nearby CAN transceiver or suitable adapter; this stage implements only the controller PCB side. Do not connect the Jetson CAN_TX/CAN_RX logic header directly to CAN_H/CAN_L. The draft CAN node is non-isolated. Ground/reference and isolation choices across the separate batteries and optional UART must be validated as one system. Do not route motor-current returns through communication cables.

## Validation

KiCad 9.0.4 exports the full netlist and renders the new sheets. Twenty-six targeted connectivity checks passed, including USB data pairing, VBUS divider, programmer selection, module reset/boot, CAN mapping, bus connectors and LEDs. USB VBUS, board 5 V, board 3.3 V and GND are distinct nets. Each symbol pin number exists in its selected footprint. The project-local TCAN1042HGV symbol's eight pin assignments were checked against TI's SOIC pin table. USB and CAN previews were visually inspected.

ERC now reports zero errors and zero warnings. Four power flags describe the externally supplied return, protected input, and actual regulator outputs; no ERC exclusions were added. Twelve additional power-connectivity checks passed, bringing the total to 38. Both regulator pin assignments were checked against the manufacturer pin tables, and all 20 new physical parts have matching footprint pad numbers. See Schematic_Both_Logos_ERC.rpt and Connectivity_Checks.txt. These checks do not constitute electrical, thermal, EMC or hardware validation.

## Controller power

J101 pin 1 is battery positive from a dedicated fused logic branch; pin 2 is battery return. This is additional to the five external motor buck branches. The circuit assumes an 8S pack reaching 29.2 V; verify the actual pack/charger label. A 1 A, >=60 VDC branch fuse is a candidate only; wire sizing, interrupt rating, inrush and fault coordination remain to be finalized.

D101 blocks reversed input polarity. D102 provides transient suppression, not sustained overvoltage regulation. The 65 V input regulator derives nominal 5 V, then the second buck derives nominal 3.3 V. See Power_Design.md for part choices, component-rating constraints and the preliminary load budget. The two converters are integrated into this PCB; they do not consume any of the user's five external DROK converters.

The existing rail LEDs now connect to real regulator output nets. Motor-current paths and Jetson battery positive remain external. Reload the project from disk to see the power sheet if it was already open.

## Driver commands and interlock

See Safety_And_Driver_Design.md for the connector map, GPIO allocation, hardware behavior and firmware startup contract. J401-J404 are provisional DRV8871 control interfaces. Eleven wheel/excavator series links are DNP, so J405-J409 are not operational until module behavior is verified. All motor power remains external.

J301 accepts only a voltage-free auxiliary contact from an external safety system; never connect 12/24 V. The PCB interlock is not a safety-rated relay and does not remove motor power. The installed direct-switch topology is documented below; DC load suitability and J301 integration remain unresolved. Green means command gate enabled; red means arm latch inhibited, not proof of a fault or a stopped motor.

The updated design passes zero-error/zero-warning ERC and checks for all 19 independent command paths, nine connector maps, PCA/direct PWM mapping, 23 interlock net groups, 106 new footprint pad mappings and 11 intentional DNP links. Power/communications checks continue to pass. No physical safety performance or dynamic circuit simulation is claimed.

## Next design work

- Sensor/end-limit wiring, paired-actuator synchronization and optional Jetson UART allocation.
- Qualify the installed direct-switch E-stop for aggregate DC load and resolve the separate J301 permissive.
- Verify wheel/excavator input behavior, excavator signal supply, wheel STOP/BRAKE/SC and final locking connectors; complete Jetson-side CAN interface.
- Exact component purchasing choices, cable/fuse/current budgets, and physical-layout completion/review.

The earlier MCU-only generator is obsolete now that these sheets have been connected; do not regenerate from it over this project.

## References

- ESP32 hardware guidelines: https://docs.espressif.com/projects/esp-hardware-design-guidelines/en/latest/esp32/schematic-checklist.html
- CP2102N power and USB circuits: https://www.silabs.com/documents/public/data-sheets/cp2102n-datasheet.pdf
- TCAN1042HGV-Q1: https://www.ti.com/lit/ds/symlink/tcan1042h-q1.pdf
- CAN protection: https://www.onsemi.com/pdf/datasheet/nup2105l-d.pdf
- USB protection: https://www.st.com/resource/en/datasheet/usblc6-2.pdf

Hardware_Requirements.md and Driver_Interfaces.md preserve user confirmations and unresolved requirements. This project is a new design, not a conversion of the prior Flux layout.

Power references: https://www.ti.com/lit/ds/symlink/lmr36510.pdf and https://www.ti.com/lit/ds/symlink/tps62160.pdf

## Latest installed E-stop topology

User confirms direct power switching: meter load positive -> latching E-stop -> fusebox positive; meter load negative -> fusebox negative. No separate contactor is installed in the reported circuit. The controller's proposed fusebox branch will lose power too. J301 must never connect to the battery-carrying switch terminals; its low-voltage permissive integration remains unresolved. See the latest section of Safety_And_Driver_Design.md. The switch's suitability for aggregate DC motor current has not been established.

## A4 wheel-direction revision
Four open-drain MOSFETs now switch the ZS-X11H Rotation inputs to ground. All 11 provisional wheel/excavator links remain DNP. ERC and updated connectivity checks pass; see Driver_Interfaces_Preview.png and the latest section of Safety_And_Driver_Design.md. Stop/brake interfaces, J301 integration and switch DC load qualification remain unresolved.

## A5 wheel Stop draft
Four driver-powered Stop request circuits have been added. Their four series links remain DNP pending module qualification; total intentional DNP links is 15. See Wheel_Stop_Design.md and Wheel_Stop_Preview.png. All 201 components export correctly; ERC reports zero errors and warnings. Physical PCB placement and routing have now started; the A6 layout status supersedes this earlier schematic-stage note.

## A6 physical routing draft complete

All 201 schematic components and four mounting holes are placed on the 160 x 100 mm four-layer PCB. Routing and copper fills are saved. PCB DRC: 0 violations, 0 unconnected items, 0 schematic-parity issues. No DRC exclusions were added. All 15 DNP links remain DNP. See PCB_Layout_Notes.md and PCB_Layout_Status.json for the reviews still required before fabrication. The native board is no longer an empty outline.

## Bill of materials
See [BOM.md](BOM.md) for the per-board grouped BOM, DNP quantities, outstanding purchasing selections, and external rover equipment. BOM_Components.json provides all 201 individual component records. This remains a draft BOM pending engineering review.

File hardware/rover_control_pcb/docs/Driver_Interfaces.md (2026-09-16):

# Driver interface research

## Confirmed module links

- Excavator: one RANSANX module described by the user as L298: https://www.amazon.com/dp/B0F21MNNY6
- Linear actuators: four DRV8871 modules: https://www.amazon.com/dp/B0G4C4KKTB
- Wheels: four ZS-X11H controllers: https://www.amazon.com/dp/B0D97PN96D

Module assignment is confirmed by the user. Physical connector order, polarity, module revisions and cable wiring are not yet verified.

## DRV8871 actuator control

TI's IC datasheet confirms two inputs, IN1 and IN2, per motor. Reserve eight independent logical control signals:

| Actuator | Logical input 1 | Logical input 2 |
|---|---|---|
| Dump 1 | DUMP_1_IN1 | DUMP_1_IN2 |
| Dump 2 | DUMP_2_IN1 | DUMP_2_IN2 |
| Excavator deployment 1 | DEPLOY_1_IN1 | DEPLOY_1_IN2 |
| Excavator deployment 2 | DEPLOY_2_IN1 | DEPLOY_2_IN2 |

These are signal names, not assigned ESP32 GPIOs or connector pin numbers.

IC truth table: 00 = coast/high impedance, then sleep; 01 and 10 = opposite drive directions; 11 = brake. Extend/retract direction depends on motor lead polarity. Both inputs low is an electrical disable, not a guarantee of mechanical load holding. End limits, feedback, paired-actuator synchronization and E-stop behavior remain to be designed.

TI specifies a 1.5 V minimum logic-high threshold, 6.5-45 V operating supply and 3.6 A peak drive. Nominal 3.3 V control is compatible with the bare IC's threshold; verify the module input circuitry before finalizing the interface. Do not treat peak drive current as continuous module capacity. Confirm each actuator's startup/stall current and the module's current-limit resistor/thermal capability.

Manufacturer source: https://www.ti.com/lit/ds/symlink/drv8871.pdf

## Excavator module

The supplied Amazon page could not be retrieved reliably. No physical pinout or electrical input specification has been verified for this exact RANSANX module. The title L298 alone is insufficient to assume a standard L298N breakout circuit, input thresholds, current rating or jumper arrangement. Retain a dedicated external excavator-driver interface, with signals pending module documentation or clear terminal-label photos.

## Power and next decisions

The four actuators and excavator motor are user-specified 12 V loads. Confirm the external 12 V supply arrangement and motor/actuator current requirements. Do not connect these loads directly to the previously proposed 24/25.6 V bus. Motor power remains off the control PCB.

The KiCad project is still a scaffold. This document defines requirements and logical signals, not validated wiring or a released circuit.

## Excavator module: seller description supplied by user

The following supersedes the earlier lack of module specifications. These are seller claims supplied in the conversation, not independently measured characteristics or evidence that the module contains an ST L298 IC.

- Dual H-bridge; one module is assigned to the single excavator motor. Use one channel provisionally; do not parallel outputs without explicit manufacturer support.
- Motor supply: 6.5-27 V, no reverse-polarity allowance. The excavator motor is specified by the user as 12 V, so plan for an external 12 V motor supply. Do not assume compatibility with the maximum charged voltage of the nominal 24/25.6 V bus.
- Control input range: 3-6.5 V, optocoupler inputs. Nominal 3.3 V is within the stated range, but input current, guaranteed thresholds and signal return wiring are unspecified. Do not finalize direct ESP32 drive or isolated-ground wiring from this description alone.
- ENA accepts PWM: 0-10 kHz; stated minimum pulse width 10 us. At 10 kHz, 10 us equals 10% duty; the text does not clarify whether the minimum applies to both high and low pulses. PWM frequency and usable duty range remain provisional.
- Forward/reverse control exists, but terminal order, number of direction inputs and braking truth table are not established by the pasted description. Reserve logical enable/PWM and direction-control functions; do not assign physical pins yet.
- Reversal: seller requires braking for more than 0.1 s AND stopping the motor before reversing. A 100 ms timer alone does not establish that the motor has stopped.
- Seller warns of back-driven motor voltage with module power off. Include this in E-stop/power-loss review; do not assume removal of driver supply alone resolves all stopping behavior.
- Claimed current: 7 A rated per channel and 50 A peak, with no peak duration or thermal test conditions. Do not use the 50 A claim for sizing.
- Seller also specifies <=40 W for a 12 V motor. This corresponds to about 3.3 A if 40 W means electrical input power; it does not reconcile cleanly with a blanket 7 A continuous claim. Actual motor current and module thermal performance need verification.
- Seller suggests input and motor fusing. Its generic 10 A fuse recommendation is not adopted as a final fuse value; coordinate with motor startup, wiring and driver capability.
- Claimed module dimensions: 55 x 55 x 16 mm; mounting holes 3 mm. This is an external module, not the controller PCB outline.

Outstanding hardware evidence: a terminal-label photo or wiring diagram; motor running/stall current; the external 12 V supply arrangement. Driver-interface circuitry remains unimplemented.

## Excavator module header: supplied product image

Viewed in the orientation of the user's product image (control header at upper left, motor terminals at right), the silkscreen appears to show a 2-column by 5-row header:

| Row, top to bottom | Left column | Right column |
|---|---|---|
| 1 | +5V | +5V |
| 2 | ENA | ENB |
| 3 | IN1 | IN3 |
| 4 | IN2 | IN4 |
| 5 | GND | GND |

This is a visual transcription, not numbered connector pins. Confirm against the physical module before making a cable. The diagram labels +5V as signal power and ENA as PWM. It does not establish whether +5V is exclusively an input, internal rail connections, optocoupler input current, braking truth table, or which output terminal block maps to each channel.

Provisional logical interface for the single excavator motor: +5V signal supply (direction/function to verify), ENA/PWM, IN1, IN2 and signal GND. Leave channel B unused, with its inactive input state to be established from module documentation. Do not parallel channels.

The image shows the separate 6.5-27 V motor supply input at lower left and two motor output terminal blocks at right. Use the user-specified 12 V motor supply, separate from controller logic supply. Do not infer galvanic isolation or join signal and power returns solely from the optocoupler description. The pictured 15 A supply fuse and 10 A motor fuse are vendor illustration values, not approved design selections.

Next evidence needed: external 12 V supply arrangement, excavator running/stall current, and confirmation of the control +5V pin function/input current. The PCB pin assignment and driver circuitry remain provisional.

## A3 driver/interlock stage - latest status
The project now has 171 schematic components across six implemented sheets, including 11 DNP links. Command interfaces for nine drivers and a hardware command interlock are drawn; sensors remain pending. This supersedes earlier scaffold-only statements. See Safety_And_Driver_Design.md for actual connector/GPIO assignments and limitations. Wheel/excavator outputs remain disconnected by DNP links until verified; external E-stop power switching is not designed yet. J301 is a voltage-free auxiliary-contact input, not a contactor coil output or 24 V input. PCB placement/routing remains undone.

## ZS-X11H V2 diagram supplied by user - latest evidence

Source: user-supplied annotated image showing ZS-X11H V2. This identifies the illustrated revision, not proof that all four installed modules have identical circuitry.

- Separate PWM throttle input on the lower control connector is labeled 2.5-5 V PWM, 50 Hz-20 kHz. The screw terminal marked 0-5 V Speed is shown with an external potentiometer. Do not interchange these inputs without verification.
- The diagram identifies an external-PWM enable jumper. Verify the physical jumper location/orientation against the installed board before changing it.
- Rotation is illustrated as a switch to driver GND.
- Stop is illustrated as a switch to driver GND.
- Brake is illustrated as a switch to the driver's own 5 V output, NOT GND.
- The driver 5 V output powers the illustrated external potentiometer. It must not be tied to the controller PCB 5 V output or to another driver's 5 V output.
- The lower control connector also shows a speed-pulse output; its amplitude, output circuit and pulses/revolution remain unknown. Do not connect it directly to ESP32 yet.
- The other lower connector is the motor Hall interface. Motor phase terminals are MA/MB/MC; power input is VCC/GND, labeled 6-60 V in the diagram.

Design consequence: keep the wheel PWM signals on ESP32 GPIO13/14/18/19. A 20 kHz initial trial is within the diagram's labeled range, subject to bench validation and confirmed duty polarity. Use the dedicated PWM throttle input. Treat Rotation and Stop as switch-emulation interfaces; the existing push-pull DIR outputs are provisional and must remain disconnected until replaced/qualified. Brake needs a separate driver-referenced high-side/contact interface if used, not the same ground-switch arrangement as Stop.

The image does not establish input current, internal pull resistors, open-circuit behavior, duty-to-speed direction, braking energy handling or which Rotation switch state gives the intended wheel direction. It therefore does not justify populating the wheel links or declaring a complete fail-safe stop. Existing DNP links are retained; no schematic wiring or component population changed in this evidence update.

Still required for the independent motor-power E-stop: button and relay/contactor model(s), coil supply and DC load ratings. Actual installed board revision and control wiring should be checked during harness definition.

## A4 wheel-direction switch revision - current implementation

Q401-Q404 (AO3400A, SOT-23) now emulate ground-switching of each ZS-X11H Rotation input. J406-J409 pin 3 connects to its MOSFET drain; pin 1 is the shared signal ground/source. Gate drive comes from the hardware-inhibited buffer through the existing 220 ohm DNP link and has a 10 kohm pulldown. These are non-isolated open-drain switches, not voltage sources or isolated relay contacts. No PCB 5 V pullup was added to Rotation.

Once the links are qualified and populated, command high closes the switch to ground; command low or hardware inhibit releases it. Open/released is a direction state, not a stop command. Determine actual wheel direction with the motor unloaded; change direction only after stopping. Verify the effects of simultaneous PWM inhibition and direction release before load testing. No behavior under loss of a ground wire is guaranteed.

The eleven wheel/excavator links remain DNP. The diagram supports this interface topology but does not establish Rotation voltage, pullup current, open-circuit state or transient levels. Validate these against the 30 V MOSFET rating with appropriate margin before use. Wheel PWM still uses the separate dedicated throttle input. STOP/BRAKE/SC and J301 low-voltage permissive integration remain unfinished.

175 schematic components now, including 11 DNP links. ERC: zero errors/warnings. Existing checks pass, plus four MOSFET gate/source/drain-to-header checks, confirmation of no direct power-rail tie on Rotation outputs, and corresponding footprint-pad checks. No physical validation or PCB routing has been completed.

The earlier build_driver_stage.py generator predates this revision and must not be rerun over the current files without porting the changes. The native KiCad files are the deliverable.

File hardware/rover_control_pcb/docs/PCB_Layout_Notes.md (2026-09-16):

# Physical PCB layout — A6 draft

The board now contains all 201 schematic components, including the 15 intentional DNP signal links, plus four provisional M3 mounting holes. It is a 160 x 100 mm, four-copper-layer board. This replaces the earlier empty-outline stage.

## Arrangement

- Top left: fused controller input and the 5 V / 3.3 V converters.
- Top edge: USB programming and the ESP32 antenna, with the library antenna keepout retained across copper layers.
- Top right: two CAN connectors, termination and transceiver.
- Left edge: six status LEDs; lower left: the voltage-free permissive connector and interlock logic.
- Lower center: PWM expansion and three output buffers.
- Bottom edge: nine driver-command connectors.
- Right edge: four wheel Stop connectors and their default-request circuits.

Inner layer 1 is a ground reference plane. Inner layer 2 carries a 3.3 V pour and some signal routes; the pour clears around those routes. Signals use front/back and inner-layer-2 copper with through vias. A bottom-layer 5 V pour distributes power around signal routes, with dedicated supply vias. Inner layer 1 remains the ground reference. Component references are on the front fabrication layer to keep the silkscreen readable; connector functions and status meanings are on silkscreen. The mechanical hole pattern and connector access still require enclosure review.

This is a physical routing draft, not a manufacturing release. Review switcher hot loops, ground-return widths, power neck-downs, USB differential routing, decoupler access, plane return paths and production stackup before fabrication. Preliminary routing rules assume 0.15 mm minimum copper clearance/track width, 0.5 mm vias with 0.25 mm drills, and some library thermal holes of 0.2 mm; confirm fabrication capability. No fabricated or powered PCB has been tested.

Motor-current paths remain off this board. The user's 10 A total battery draw is a planning assumption, not a verified worst-case load or a DC rating for the E-stop. The physical layout does not resolve the existing E-stop interruption rating or the J301 permissive integration. All 15 DNP links remain DNP. Sensor/end-limit circuits and firmware remain outstanding.

See PCB_Both_Logos_DRC.json and PCB_Layout_Status.json for the latest measured routing/check status. Schematic ERC and PCB DRC are separate checks; a clean schematic does not mean the PCB is ready to fabricate.

The draft uses 0.15 mm signal tracks. Sixty power-track segments were widened to 0.5 mm where clearance allowed, and a bottom 5 V pour was added. Short power neck-downs and regulator current paths still require thermal/current-capacity and switching-loop review before fabrication; connectivity alone is not sufficient. The preview may omit unavailable component models, including the CAN connector bodies.

## Final A6 connectivity check

KiCad 9.0.4 PCB DRC, with schematic-parity checking enabled: zero violations, zero unconnected items, zero schematic-parity issues. No violations were excluded to obtain this result. All 201 schematic components are placed; four board-only mounting holes are additional. All 15 intended DNP links remain marked DNP. This is completion of the physical routing draft, not electrical/thermal/EMC validation or fabrication approval.

PCB_Front_Logo.png and PCB_Blue_White_Routing.svg show front silkscreen and front/back routing for review; inner routes and pours are visible in the native board. PCB_Placement.csv lists all positions. Component references are on F.Fab.

## Blue appearance update

The PCB specifies blue solder mask and white silkscreen on both sides. PCB_Front_Logo.png and PCB_Blue_White_Routing.svg illustrate front and back routing in white/light blue on a blue background; these trace colors are for visualization. Physical copper traces are covered by solder mask, except exposed pads. Inner-layer routes and copper pours are omitted from this illustration for readability.

J402 (DUMP2) is connected: pins 2 and 3 have back-copper signal routes, and pin 1 connects to ground through the ground plane. The prior top-only preview hid these connections.

The user confirmed the ESP32 with the metal shield. Retain the directly soldered ESP32-WROOM-32E-N4 module; no bare-QFN redesign or plug-in development board is requested. This appearance update does not change electrical connectivity.

ESP32 visualization fix: bundled the ESP32-WROOM-32E STEP model and replaced the missing WROOM-32D model reference. Applied +2.99 mm model Y offset to account for the library footprint origin difference. Electrical pads and routing are unchanged. The metal shield and integrated module antenna are part of this assembly; no bare-chip RF redesign was performed.

## Team logo
LOGO1 is a 48 mm monochrome version of the supplied UHCL logo on B.Silkscreen, centered at (137, 91) mm and readable from the rear. It is board-only artwork excluded from BOM and placement. Source and monochrome artwork are in artwork/. Latest logo DRC: zero violations and zero unconnected items. Fine lettering/0.12 mm artwork detail still needs silkscreen capability review. The front title and electrical design are preserved.

Front logo trial: LOGO2, 23 mm wide, F.Silkscreen, centered at (140.5, 85.5) mm. Back logo retained. Both logo footprints are excluded from BOM and assembly placement. No copper or component placement changed. DRC reports zero violations and zero unconnected items. The full emblem's fine lettering at 23 mm may not reproduce reliably in silkscreen; simplify or omit the front trial before manufacture if the fabricator cannot resolve it.

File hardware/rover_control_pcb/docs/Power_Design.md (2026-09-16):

# Controller power design - schematic draft

## Power path and interfaces

Dedicated fusebox logic branch -> J101 (+ pin 1, return pin 2) -> D101 reverse-polarity diode -> protected input -> U101 5 V buck -> U102 3.3 V buck.

This circuitry powers the controller only. It is separate from all five external DROK motor buck converters and from the Jetson's V-mount battery. No motor power goes through this PCB. CAN and programming connections still share signal ground as described in README.md.

## Component choices

| References | Draft selection | Function / constraint |
|---|---|---|
| J101 | Phoenix MKDS 1.5, 2-position, 5 mm pitch footprint | Dedicated fused input; verify exact purchasing part and harness |
| D101 | STPS1H100A, SMA | 100 V, 1 A reverse-polarity series Schottky |
| D102 | Littelfuse SMBJ33A, SMB | Unidirectional TVS: cathode to protected positive, anode to GND |
| C101 | 22 uF / 63 V electrolytic, D8 mm, P3.5 mm | Input bulk and damping; exact ESR, ripple rating and mechanical part pending |
| U101 | LMR36510ADDAR, TI DDA | 65 V operating input, 400 kHz, 1 A buck |
| L101 | Bourns SRN6045TA-220M, 22 uH | 2.3 A typical thermal rating, 3.3 A typical saturation rating |
| C102, C103 | 2.2 uF / 100 V X7R; 220 nF / 100 V X7R | Local input bypass; place immediately at U101 VIN/PGND |
| C104, C105 | 1 uF / 10 V; 100 nF / 16 V | Internal VCC bypass; bootstrap capacitor from BOOT to SW |
| C106, C107 | Two 22 uF / 25 V X7R, 1210 | 5 V output filtering |
| R101, R102 | 100 kohm / 24.9 kohm, 1% | Nominal 5.016 V target |
| U102 | TPS62160DGKR, 8-pin VSSOP/MSOP | 1 A adjustable buck, supplied by 5 V |
| L102 | Bourns SRN6045TA-3R3Y, 3.3 uH | Oversized preliminary inductor; nominal tolerance +/-30%, footprint 6 mm class |
| C108, C109 | 10 uF / 16 V X7R; 22 uF / 16 V X7R | 3.3 V stage input/output bypass |
| R103, R104 | 312 kohm / 100 kohm, 1% | Nominal 3.296 V target |

Regulator power-good pins are intentionally unused. Their enable pins follow their respective inputs. The input supply remains present when motor motion is disabled; the independent E-stop design is still pending. This sheet does not implement battery undervoltage cutoff.

## Preliminary budget

Reserve 600 mA on 3.3 V for ESP32, CP2102N, logic and indicators, plus 150 mA directly on 5 V for CAN and indicators. These are design allowances, not measured currents.

Assuming 80% efficiency for the 3.3 V converter, this requires about 0.643 A at the 5 V regulator. Both stages use 1 A-rated ICs, but load limits depend on PCB cooling and selected passives. Future driver-interface circuitry must fit the remaining budget or trigger resizing. There is no spare-power connector for external loads.

A conservative two-stage planning calculation gives roughly 0.18 A input at 24 V using 80% first-stage efficiency and about 0.7 V diode drop. Battery input current is not equal to the 3.3 V output current. Startup/inrush and transient load peaks require measurement.

## Ratings and release requirements

- Battery maximum is provisionally 29.2 V for 8S LiFePO4; confirm actual battery and charger labels.
- Candidate external fuse: 1 A, at least 60 VDC. This is not a finalized fuse selection; verify interruption capacity, wire protection, inrush and diode/TVS fault coordination.
- SMBJ33A has 33 V standoff and a specified 53.3 V clamp at 11.3 A for its rated pulse. Actual clamping depends on surge waveform, source impedance, wiring and layout; it does not prove immunity to motor transients or sustained overvoltage.
- Use exact capacitors meeting effective capacitance after DC bias, ESR, temperature and ripple requirements. Nominal values and voltage ratings alone do not finalize the BOM. The first-stage output capacitor choice follows TI's 5 V nominal recommendation; account for downstream capacitance in stability testing.
- L102 tolerance and effective output capacitance must be evaluated together against TI's LC stability guidance. Check startup, load steps and light-load operation; the selected inductor is preliminary and can be reduced after validation.
- Keep U101 VIN bypass/hot loop short, SW copper small, and BOOT capacitor close. Connect its exposed pad to the ground plane with thermal vias. Route feedback from the output capacitor separately from switch-current paths. Do the same for U102 VOS/FB and its analog-ground return.
- Test current-limited startup, both rail voltages, ESP32 transmit bursts, USB enumeration/programming, CAN operation, temperature and shutdown before integration with motor power. Transient validation needs representative wiring and load conditions.

KiCad ERC is zero-error/zero-warning. Connectivity and footprint-pad checks pass. The PCB outline is still empty: no placement, routing, thermal verification or fabrication release has been completed.

## Manufacturer references

- TI LMR36510: https://www.ti.com/lit/ds/symlink/lmr36510.pdf
- TI TPS62160: https://www.ti.com/lit/ds/symlink/tps62160.pdf
- ST STPS1H100: https://www.st.com/resource/en/datasheet/stps1h100.pdf
- Littelfuse SMBJ33A: https://www.littelfuse.com/products/overvoltage-protection/tvs-diodes/surface-mount/smbj/smbj33a
- Bourns inductors: https://www.bourns.com/docs/product-datasheets/srn6045ta.pdf

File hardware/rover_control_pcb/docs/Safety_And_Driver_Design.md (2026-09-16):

# Driver commands and hardware interlock - A4 circuit draft

This stage adds command circuitry for nine external motor drivers and a PCB command interlock. It does not complete the external E-stop power-disconnect system. Motor currents, relay/contactor details and module harness verification remain open. The PCB is still unplaced and unrouted.

## Board-side connector map

These are newly assigned PCB pin numbers, not a transcription of module header order. Headers are provisional 2.54 mm prototype footprints; select locking rover harness connectors before layout release.

| Connector | Load | Pin 1 | Pin 2 | Pin 3 | Pin 4 |
|---|---|---|---|---|---|
| J401 | Dump actuator 1 | GND | IN1 | IN2 | - |
| J402 | Dump actuator 2 | GND | IN1 | IN2 | - |
| J403 | Excavator deployment actuator 1 | GND | IN1 | IN2 | - |
| J404 | Excavator deployment actuator 2 | GND | IN1 | IN2 | - |
| J405 | Excavator motor | GND | ENA/PWM | IN1 | IN2 |
| J406 | Wheel 1 | GND | SPEED/PWM | DIR | - |
| J407 | Wheel 2 | GND | SPEED/PWM | DIR | - |
| J408 | Wheel 3 | GND | SPEED/PWM | DIR | - |
| J409 | Wheel 4 | GND | SPEED/PWM | DIR | - |

All commands pass through SN74AHCT244PWR buffers powered by 5 V. Wheel direction commands then drive Q401-Q404 open-drain MOSFETs; their connector pins no longer receive push-pull voltage outputs. Their TTL-compatible inputs accept the 3.3 V commands. Each command has a 10 kohm input pulldown, 220 ohm output series resistor, and a 10 kohm pulldown after the series resistor. For wheel DIR, that pulldown is on the MOSFET gate, not on the connector drain. Hardware disable makes the buffer outputs high impedance; the pulldowns then establish low provided the external modules do not overpower them. Harness opens require module-side pulldowns too.

The eleven series resistors for J405-J409 are explicitly DNP (do not populate), keeping unverified wheel/excavator commands disconnected in this draft. These modules cannot be operated through these headers until their input behavior is verified and the links are deliberately fitted. Actuator links are populated provisionally based on the DRV8871 IC specifications; verify the purchased module circuitry and terminal order before wiring.

DRV8871 inputs 00 produce coast/sleep, not mechanical holding or an emergency brake. Its recommended logic input range extends to 5.5 V. The excavator module's optocoupler current and +5 V signal-power pin remain unresolved: J405 intentionally does not export a supply. The unused excavator channel must be disabled at the module. Reversal requires a stopped motor and the seller's stated dead time, not merely swapping bits while moving.

The newly supplied ZS-X11H V2 diagram identifies a dedicated PWM throttle input labeled 2.5-5 V, 50 Hz-20 kHz, plus an external-PWM jumper. The screw-terminal 0-5 V Speed input is shown separately with a potentiometer. Rotation and Stop are illustrated as switches to driver GND; Brake is illustrated as a switch to the driver's own 5 V output. See Driver_Interfaces.md for the full evidence update.

Wheel DIR now uses Q401-Q404 open-drain switches to GND; the gate-drive links remain DNP pending module qualification. STOP/BRAKE/SC interfaces are not implemented. Do not connect the driver's onboard 5 V output to the PCB's 5 V rail. PWM duty polarity, open-circuit behavior, control currents and speed-output voltage remain unverified. Wheel speed zero is not claimed as the complete E-stop mechanism.

## PWM and GPIO assignment

PCA9685PW at 7-bit I2C address 0x40 provides 15 assigned outputs. All address pins are grounded; EXTCLK is grounded because the internal oscillator is used. Its OE pin is low; separate physical buffers enforce command inhibition regardless of PCA output configuration. The expander can retain stale commands across an ESP32 reset, so explicit initialization is essential.

| PCA channel | Function |
|---|---|
| 0, 1 | Dump 1 IN1, IN2 |
| 2, 3 | Dump 2 IN1, IN2 |
| 4, 5 | Deployment 1 IN1, IN2 |
| 6, 7 | Deployment 2 IN1, IN2 |
| 8 | Excavator ENA/PWM |
| 9, 10 | Excavator IN1, IN2; static full-off/full-on |
| 11-14 | Wheel 1-4 DIR; static full-off/full-on |
| 15 | Unused, no connection |

Initial actuator/excavator PWM target is about 1 kHz. With a nominal 25 MHz PCA clock, PRE_SCALE=5 gives about 1017 Hz. Actual clock tolerance applies. All PWM channels share this frequency. At that frequency, the excavator seller's 10 us pulse requirement limits usable non-static duty near the ends; provisionally keep both high and low pulses at least 10 us. Full-off and full-on are separate static modes. DRV8871 pulse limits and actuator noise/heating must also be checked. Paired actuators need measured position or other synchronization safeguards; issuing equal PWM is not position synchronization.

| ESP32 GPIO | Function |
|---|---|
| 16, 17 | I2C SDA, SCL; 4.7 kohm pullups to 3.3 V |
| 13, 14, 18, 19 | Wheel 1-4 speed PWM; dedicated PWM throttle; initial 20 kHz trial, pending module verification |
| 4 | Software watchdog toggle |
| 27 | ARM_REQUEST, default pulldown |
| 34 | SAFETY_OK input |
| 35 | MOTION_ENABLED readback |
| 21, 22 | Existing CAN TX, RX |
| 23, 32 | Existing heartbeat LED, CAN LED |
| 1, 3 | Existing USB/service UART |

GPIO25, GPIO26, GPIO33 and input-only GPIO36/39 remain available in the draft; final sensor allocation and optional Jetson UART are pending. Boot straps and flash-reserved pins are not used for new motor commands.

## Hardware interlock behavior

J301 is a two-wire, voltage-free auxiliary-contact input. Pin 1 receives 3.3 V through 1 kohm; pin 2 returns to a 10 kohm pulldown, 10 nF filter and Schmitt buffer. Closed contact produces about 3.0 V at the Schmitt input. Contact current is about 0.3 mA: use a contact rated for low-level signals. This is a short, protected local connection to a safety device, not a general-purpose long field cable or 24 V input. No external voltage is allowed. Field ESD/transient protection remains to be finalized with the harness.

The expected external auxiliary contact closes only when an independent E-stop system permits motion. An open contact or broken wire inhibits commands. A short across the wires is not detected. This single-channel input, common logic and shared enable net are not a safety-rated E-stop controller and do not provide single-fault tolerance.

U302 (SN74LVC1G123DCUR) monitors rising edges from GPIO4 with A held low. R303=200 kohm and C303=1 uF give a nominal timeout around 0.2 seconds; the exact minimum/maximum must be characterized across tolerance, voltage and temperature. The timing capacitor connects between CEXT and RCEXT, not to ground. The timer's clear pin follows ESP_EN.

U303 clears the arm latch unless all three conditions are high: SAFETY_OK, watchdog Q, and ESP_EN. U304 latches an ARM_REQUEST rising edge, with D and preset tied high. Any loss of a permissive clears it asynchronously. Restoring the permissives alone does not set it again. U305 additionally requires ARM_REQUEST to remain high, plus ESP_EN, before enabling the outputs. Dropping ARM_REQUEST therefore inhibits commands immediately without waiting for the watchdog.

Q301 (AO3400A, characterized at 2.5 V gate drive) translates the enable into the common active-low buffer enable. R306 pulls that enable to 5 V by default; R307 holds the MOSFET gate low when undriven.

| Condition | Intended command behavior |
|---|---|
| Power-up | Inhibited; requires valid permissives and new arm edge |
| Safety contact opens | Latch clears; buffers disable |
| Heartbeat stops high or low | Watchdog expires; latch clears; buffers disable |
| ESP_EN reset asserted | Latch clears and final enable drops |
| ARM_REQUEST drops | Final enable drops immediately |
| Contact/heartbeat restored, ARM held high | Latch remains cleared; no automatic re-arm |
| Valid permissives plus new intentional arm edge | Commands may pass through buffers |

Internal ESP32 reset does not necessarily pull ESP_EN low. Default GPIO27 pulldown inhibits as GPIOs return to reset state, and missing heartbeat provides the timeout path. Power ramps, brownouts, GPIO boot behavior, latch recovery timing and transistor/buffer enable behavior still need hardware validation. No worst-case stopping time or safety integrity level is claimed.

D301 green indicates the PCB command gate is enabled. D302 red indicates the arm latch is cleared; it is an INHIBITED indicator, not a comprehensive fault lamp. Because ARM can drop before the watchdog clears the latch, both LEDs can temporarily be off. Neither LED verifies contactor position or that a motor is stationary.

## Firmware contract (not implemented firmware)

1. On every boot, force ARM_REQUEST low, wheel PWM low, and watchdog low. Wait until the previous latch/watchdog state has cleared; do not immediately revive an old watchdog pulse train.
2. Initialize I2C and PCA9685 in the disabled state; set every output full-off, non-inverted, push-pull. Configure frequency while asleep as required, then wake and wait for the oscillator. Disable unused group-call features or handle them deliberately.
3. Read back critical configuration and confirm communication. Confirm external safety permission and fresh operator commands. Do not re-use pre-reset motion requests.
4. Service the watchdog from the successful main control cycle, not an autonomous PWM peripheral or an unconditional timer interrupt. Toggle at intervals giving a rising edge about every 20 ms only while command freshness, required feedback, I2C success and local safety checks are valid.
5. A fresh explicit arm request may then raise GPIO27. Verify MOTION_ENABLED readback before motion. Restoring E-stop or communication alone must not auto-arm.
6. On any fault, lower ARM_REQUEST, stop the heartbeat and clear commands when communication is available. An I2C bus failure must not prevent GPIO27 from dropping.
7. Apply stopped-motor direction sequencing, actuator limits and pair-synchronization logic. Define and validate CAN command timeout, end limits and feedback before load testing.

## External E-stop integration still required

The independent E-stop system must remove or otherwise safely inhibit energy to all nine motor branches without relying on ESP32, CAN or this PCB. Its auxiliary contact feeds J301. Keep controller diagnostics powered from an appropriately protected branch if the final system architecture permits it.

The physical button, relay/contactor or safety relay, coil voltage, DC switching ratings, reset method, feedback contacts, motor stopping behavior and stored-energy handling are not yet specified. The existing fusebox and converters do not perform this function. Do not invent coil-terminal wiring or choose a contactor from the battery's Ah capacity. The excavator vendor's back-drive warning and mechanical load holding need to be addressed in the external design.

E-stop button link received: BAOMAIN B00NTT91Y0; see the latest evidence below. Pending user information: separate relay/contactor model and confirmation of button latching action. The ZS-X11H V2 diagram now identifies terminals and the PWM range; installed revision and harness/control behavior still require verification. Motor stall currents, feedback/end-limit hardware and final locking connectors are also needed before release.

## Validation

175 schematic components, including 11 DNP links. Zero KiCad ERC errors/warnings. Existing 38 power/communications connectivity checks pass. Additional checks cover all 19 command paths, all nine connector maps, 15 PCA channels, four ESP32 PWM channels, I2C/address pins, 23 interlock net groups, independent signal nets, 106 new footprint pad mappings and the custom logic pin tables. No dynamic circuit simulation, physical E-stop performance test, PCB DRC or compliance validation has been completed.

## Primary references

- DRV8871: https://www.ti.com/lit/ds/symlink/drv8871.pdf
- PCA9685: https://www.nxp.com/docs/en/data-sheet/PCA9685.pdf
- Output buffers: https://www.ti.com/lit/ds/symlink/sn74ahct244.pdf
- Schmitt buffer: https://www.ti.com/lit/ds/symlink/sn74lvc1g17.pdf
- Watchdog monostable: https://www.ti.com/lit/ds/symlink/sn74lvc1g123.pdf
- Re-arm latch: https://www.ti.com/lit/ds/symlink/sn74lvc1g74.pdf
- AND gates: https://www.ti.com/lit/ds/symlink/sn74lvc1g11.pdf
- Enable MOSFET: https://www.aosmd.com/sites/default/files/res/datasheets/AO3400A.pdf

The user-supplied module listing and photos remain the source of module-specific claims; IC datasheets alone do not verify a seller's breakout wiring.

## E-stop button identified from user link

User supplied Amazon ASIN B00NTT91Y0: BAOMAIN enclosed red mushroom E-stop station, advertised with 1 NO and 1 NC contact and 660 V / 10 A markings. This identifies the button station, not a separate motor-power relay/contactor.

Amazon currently describes press-to-stop / clockwise twist-to-reset. A similar BAOMAIN manufacturer page instead says momentary and specifies AC 660 V / 10 A. Exact equivalence is not established, so confirm that the installed button stays latched when pressed and requires deliberate reset. Do not infer a DC motor interruption rating from the generic voltage/current markings.

Proposed role: the normally closed contact participates in the external de-energize-to-stop control circuit, subject to verified DC control-load rating and final safety architecture. Do not route all rover motor current through this button based on the listing. A 1NO+1NC assembly does not provide two independent NC channels. Do not reuse the same NC terminals simultaneously for a powered coil circuit and PCB J301; J301 accepts a separate voltage-free permissive contact only.

The actual relay/contactor or safety relay, coil supply, load ratings and feedback/reset arrangement remain unknown. No contactor wiring or PCB changes were made based on this link. Needed clarification: whether a separate relay/contactor is already installed and its model, and confirmation of the physical button's latching action.

Sources:
- https://www.amazon.com/dp/B00NTT91Y0
- https://baomain.com/products/momentary-emergency-stop-switch (similar manufacturer product; exact match unconfirmed)

## Confirmed installed E-stop wiring - supersedes relay uncertainty

The user confirms that battery power passes directly through the E-stop switch. The DC meter has four terminals: two connect to the battery; of the remaining two, the positive feed goes through the switch to fusebox positive, and the negative feed goes directly to fusebox negative. Terminal functions here describe the user's wiring; the meter model, printed terminal numbers and internal shunt arrangement are not verified.

Functional topology:
Battery +/- -> DC meter battery-side connections.
DC meter load-side positive -> latching E-stop switch -> fusebox positive.
DC meter load-side negative -> fusebox negative.
Fusebox -> four wheel controllers directly, plus five buck/driver branches for four actuators and the excavator motor.

There is no separate relay/contactor in the reported installation. Pressing the E-stop opens the motor distribution feed; twisting restores that feed. This confirms maintained/latching behavior on the installed button despite inconsistent web descriptions. It does not establish motor stopping time or suitability of the switch for the DC interruption duty.

The switch carries the aggregate current of every load downstream of that fusebox, not just a control signal. Its exact DC make/break rating, motor startup/stall current, converter inrush and wiring protection must be checked before accepting this as the final power-cutoff design. The advertised generic 660 V / 10 A marking is not verification for this DC motor load. Main protection ahead of the switch/meter is not yet established by the described topology; do not infer its absence or presence.

The existing proposed controller logic feed comes from a dedicated branch of this same fusebox. Under this topology, pressing E-stop also removes controller PCB power; restoring it causes a cold start. The separate Jetson V-mount supply is unaffected by this switch as described. Keeping controller diagnostics alive would require an explicitly redesigned, separately protected upstream logic branch; that change has not been made.

PCB J301 remains an unpowered dry-contact permissive input; it must not connect to either battery-carrying switch terminal. No spare NC permissive contact or external auxiliary relay is established by this wiring. The advertised spare NO contact is not automatically a suitable closed-when-permitted contact for J301. J301 therefore remains an unresolved integration point, and the current draft stays inhibited without a valid permissive; do not bypass it silently.

No schematic connectivity or component-population changes were made in this evidence update. Next engineering work is to validate the direct-switch DC load rating and resolve the independent low-voltage permissive interface, then finish the wheel switch-emulation circuitry. Required motor/current and switch contact-block data remain pending.

## A4 wheel-direction switch revision - current implementation

Q401-Q404 (AO3400A, SOT-23) now emulate ground-switching of each ZS-X11H Rotation input. J406-J409 pin 3 connects to its MOSFET drain; pin 1 is the shared signal ground/source. Gate drive comes from the hardware-inhibited buffer through the existing 220 ohm DNP link and has a 10 kohm pulldown. These are non-isolated open-drain switches, not voltage sources or isolated relay contacts. No PCB 5 V pullup was added to Rotation.

Once the links are qualified and populated, command high closes the switch to ground; command low or hardware inhibit releases it. Open/released is a direction state, not a stop command. Determine actual wheel direction with the motor unloaded; change direction only after stopping. Verify the effects of simultaneous PWM inhibition and direction release before load testing. No behavior under loss of a ground wire is guaranteed.

The eleven wheel/excavator links remain DNP. The diagram supports this interface topology but does not establish Rotation voltage, pullup current, open-circuit state or transient levels. Validate these against the 30 V MOSFET rating with appropriate margin before use. Wheel PWM still uses the separate dedicated throttle input. STOP/BRAKE/SC and J301 low-voltage permissive integration remain unfinished.

175 schematic components now, including 11 DNP links. ERC: zero errors/warnings. Existing checks pass, plus four MOSFET gate/source/drain-to-header checks, confirmation of no direct power-rail tie on Rotation outputs, and corresponding footprint-pad checks. No physical validation or PCB routing has been completed.

The earlier build_driver_stage.py generator predates this revision and must not be rerun over the current files without porting the changes. The native KiCad files are the deliverable.

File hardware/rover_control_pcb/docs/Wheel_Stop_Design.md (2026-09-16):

# Wheel Stop interface draft — A5

Four channels use the ZS-X11H diagram supplied by the user, which shows Stop switched to ground. Actual module polarity, input current, startup behavior and stopping performance still require verification. This circuit is a Stop request, not a motor-power disconnect or a safety-rated function.

## Connections

J801/J802/J803/J804 correspond to wheels 1/2/3/4. Pin 1 is signal GND, pin 2 goes to that driver's STOP input, and pin 3 goes to that driver's 5 V OUT. These are provisional 2.54 mm prototype headers. Each driver 5 V net is separate from every other driver and from PCB 5 V. Grounds are shared; the system is not galvanically isolated.

Each AO3400A Stop MOSFET has a 47 kO gate pull-up powered by its own driver. An LTV-817S-B optocoupler pulls the gate down while motion is permitted. A common AO3400A driven by hardware MOTION_ENABLED lights all four optocouplers through individual 680 O resistors. Approximate LED load is 22 mA total on PCB 5 V, within the preliminary 150 mA direct-5-V allocation; the complete load budget still needs reconciliation. Optocoupler ordering suffix, temperature margins and package dimensions require procurement review.

## Intended states after qualification and link population

| Driver 5 V | Hardware motion enable / PCB supply | Stop request |
|---|---|---|
| Present | Disabled or PCB unpowered | MOSFET closes Stop to ground |
| Present | Enabled, PCB rails valid | Optocoupler opens Stop switch |
| Absent | Any | Not guaranteed by this circuit |

R821–R824 are deliberately not populated. As delivered, these four Stop connector signals are disconnected from their MOSFETs. Do not interpret the draft as providing operational stopping protection. The 11 wheel/excavator command links also remain DNP.

A broken signal ground, missing driver 5 V wire, stuck enable, or component fault can defeat the request. No brake or speed-feedback circuit is included. The user diagram shows Brake switched to driver 5 V, so it must not be treated as another ground-switch input. Stop release is common to all wheels; per-wheel speed remains controlled by PWM.

## E-stop and permissive

The confirmed installed circuit routes meter load positive through the latching push/twist E-stop directly to fusebox positive. Meter load negative goes directly to fusebox negative. There is no separate contactor. The proposed controller branch on that fusebox also loses power when pressed; Jetson uses its separate battery. Restart must require a fresh arm command and cleared stale outputs.

Aggregate DC interruption capability of the installed switch is not established. J301 is a 3.3 V voltage-free-contact input, not a battery input. Its valid closed-when-permitted contact arrangement remains unresolved; it has not been bypassed. The existing power-switch terminals must not connect to J301. Without a valid permissive, the draft stays inhibited.

## Qualification before assembly release

Verify each actual driver's Stop polarity, open/closed behavior, voltage and sink current with a current-limited test setup and safely restrained/unloaded mechanics. Check startup, disarm, watchdog expiry, MCU reset, controller power loss, driver power loss and restoration. Confirm no automatic restart after power or permissive restoration. Check stopping time under representative load separately. Populate links only after compatibility is established. Bench measurements, firmware and physical stopping tests have not been performed.

KiCad ERC and netlist checks verify connections and pad-number coverage only; they do not validate the above operating behavior. PCB placement and routing remain pending.

References: user-supplied ZS-X11H diagram; AO3400A datasheet https://www.aosmd.com/sites/default/files/res/datasheets/AO3400A.pdf ; Lite-On LTV-8X7 series https://optoelectronics.liteon.com/upload/download/DS-70-96-0016/LTV-8X7%20series%20%20Rev.S.PDF .

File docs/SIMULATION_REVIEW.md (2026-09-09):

# Full rover simulation revision

This branch contains a **reference-derived reconstruction**, not the original complete mechanical assembly. It is an integration draft. Verification runs on GitHub Actions using ROS 2 Humble / Gazebo 11 and KiCad 9. See `docs/validation/README.md` for measured results and remaining limits.

## Source and dimensions

The supplied ISMCR manuscript specifies four BLDC drive motors, 40 kg reported total mass, 0.87 × 0.75 × 0.75 m reported envelope, and 304.8 mm diameter × 100 mm wide wheels with 12 grousers. The supplied images establish the frame, bucket and conveyor arrangement. They do not define manufacturing geometry. The reconstruction's extended conveyor and wheel track exceed the reported envelope; those positions need reconciliation with the original assembly before claiming dimensional fidelity.

The current reinforced wheel has 12 fins at 30-degree intervals, 22 mm radial projection, 100 mm width and 248 mm outer diameter to fit a nominal 256 mm print bed. It deliberately differs from the manuscript wheel diameter. See `cad/full_rover/WHEEL.md` for thicknesses, the separate 300 mm lab version and print placement. The 44 mm pre-cut value comes from earlier generated CAD, not a measured original wheel. Bore and bolt pattern are provisional. The generated enclosures have vented lids but lack verified board mounting bosses, connector openings and fastening features. Do not print them as fitted replacement enclosures yet.

## Build on Ubuntu 22.04 / ROS 2 Humble

```bash
sudo apt update
sudo apt install ros-humble-gazebo-ros-pkgs ros-humble-gazebo-dev \
  ros-humble-rviz2 ros-humble-joint-state-publisher-gui \
  ros-humble-cv-bridge python3-opencv python3-colcon-common-extensions
source /opt/ros/humble/setup.bash
cd ros2_ws
rosdep install --from-paths src --ignore-src -r -y
colcon build --symlink-install --packages-up-to lunabotics_description
source install/setup.bash
ros2 launch lunabotics_description simulation.launch.py
```

Display only, with joint sliders:

```bash
ros2 launch lunabotics_description display.launch.py
```

Opt-in experimental mission, in a simulation-only ROS domain without physical drivers:

```bash
ros2 launch lunabotics_description simulation.launch.py autonomy:=true
```

The mission waits for LiDAR and odometry, rotates to scan, advances with excavation enabled, checks a simulated transferred-rock count, searches for four blue posts, approaches them, turns the rear toward the target, then releases the electronic latch, tips and lowers the bucket, waits for passive door closure and re-latches. Excavator deployment and retraction use a second actuator pair. Faults latch until node restart. This is a local reactive demonstration, **not Nav2 navigation, SLAM, or general terrain planning**. The gray/tan regolith detector remains a development baseline; excavation-zone selection in this demonstration uses the initial scene arrangement, not validated terrain recognition.

## Simulation scope

- Ground and rocks use terrestrial gravity; the arena is a 10 × 6 m custom test space, not an official competition field.
- Four blue posts make the HSV baseline testable. Real post appearance and geometry require calibrated detection.
- Wheel rotation, bucket tipping, passive top-hinged door opening and illustrative actuator extension have URDF joints.
- Scoops advance and reset along a prismatic path. This does not model a full closed-loop chain or chain tension.
- The C++ plugin scripts rock pickup and transfer. Collision geometry permits gravity discharge from the bucket, but discharge success has not been demonstrated.
- Actuator extension is visually proportional to bucket angle; linkage closure, force and synchronization are not solved.
- Gazebo odometry is simulation data. The manuscript deliberately omits physical wheel-encoder odometry because of slip. LiDAR/inertial localization and Nav2 remain future integration work.
- The simulation mission shares conventional topic names with legacy firmware. Use a separate ROS domain; there is no physical actuator bridge in this revision.

## Files and reproducibility

| Location | Contents |
| --- | --- |
| `cad/` | Five preserved original project meshes with generated CAD separated into `full_rover/` and `autonomy_rover/` |
| `ros2_ws/src/lunabotics_description/` | URDF, meshes, Gazebo plugin, arena, RViz and launch files |
| `ros2_ws/src/lunabotics_autonomy/` | Existing perception with sensor QoS, fail-closed LiDAR and opt-in simulation state machine |
| `docs/electrical/rev_c/` | KiCad system wiring and machine-readable module connections |
| `tools/build_description.py` | Regenerate URDF and copy meshes |
| `tools/build_arena.py` | Regenerate arena |
| `tools/build_wiring_schematic.py` | Regenerate KiCad wiring draft |

The original STL files and uploaded Rev-B schematic remain available for comparison.

## Review gates

1. Compile the Gazebo plugin and launch the scene on Humble. Verify clock, robot TF, joint states, scan and image topics.
2. Verify wheel direction, stable contacts, conveyor path, retained material and actual discharge into the designated pad.
3. Test camera loss, scan loss, invalid scans, obstacles and actuator command loss.
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

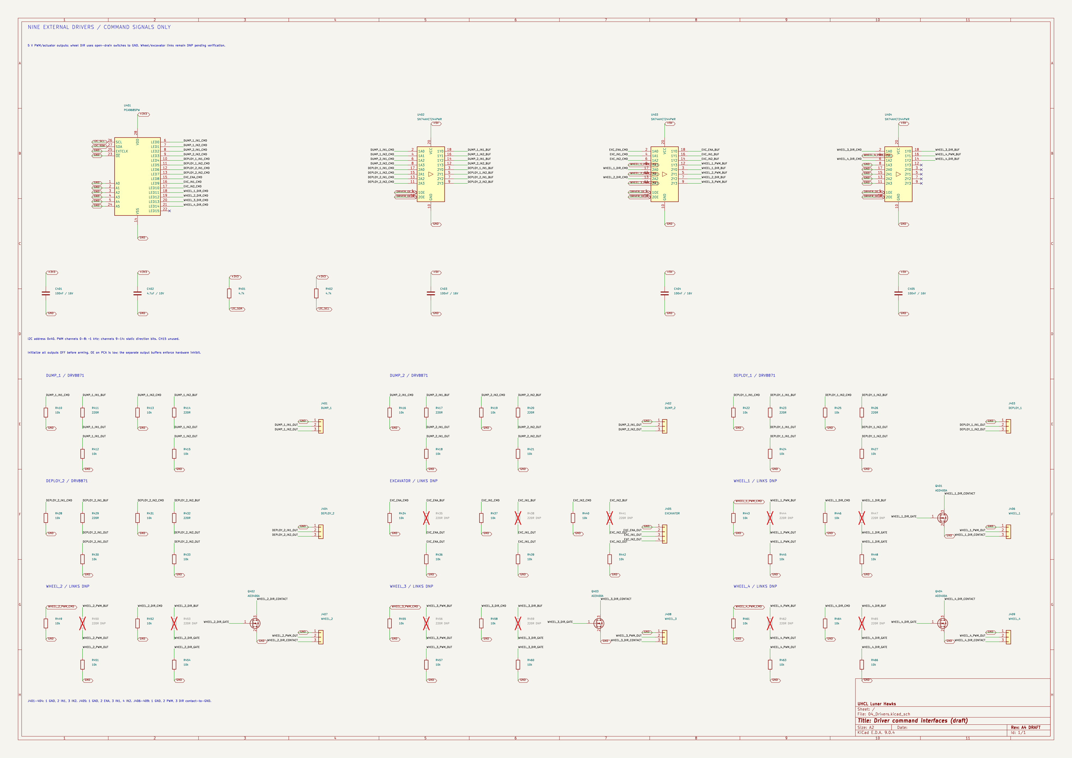
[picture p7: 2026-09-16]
hardware/rover_control_pcb/images/schematic/Driver_Interfaces_Preview.png

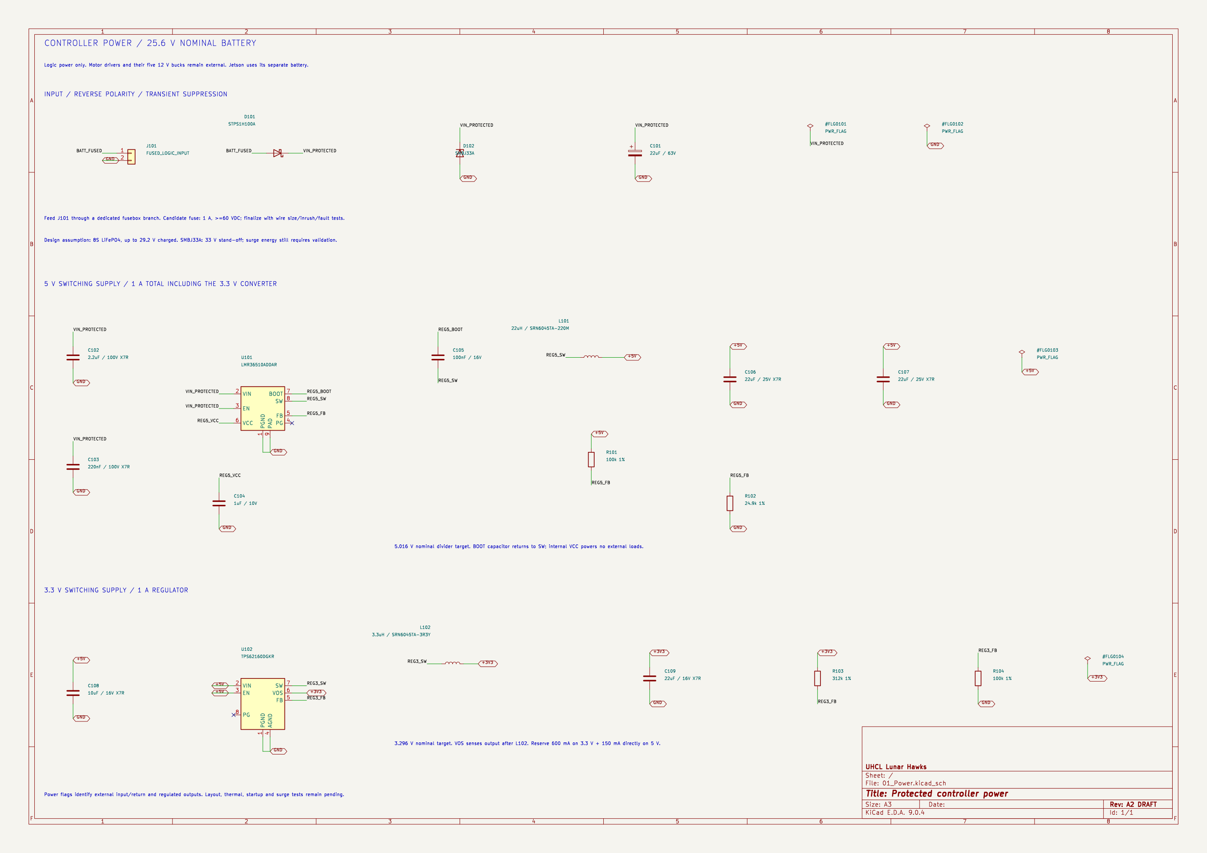
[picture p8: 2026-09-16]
hardware/rover_control_pcb/images/schematic/Power_Preview.png

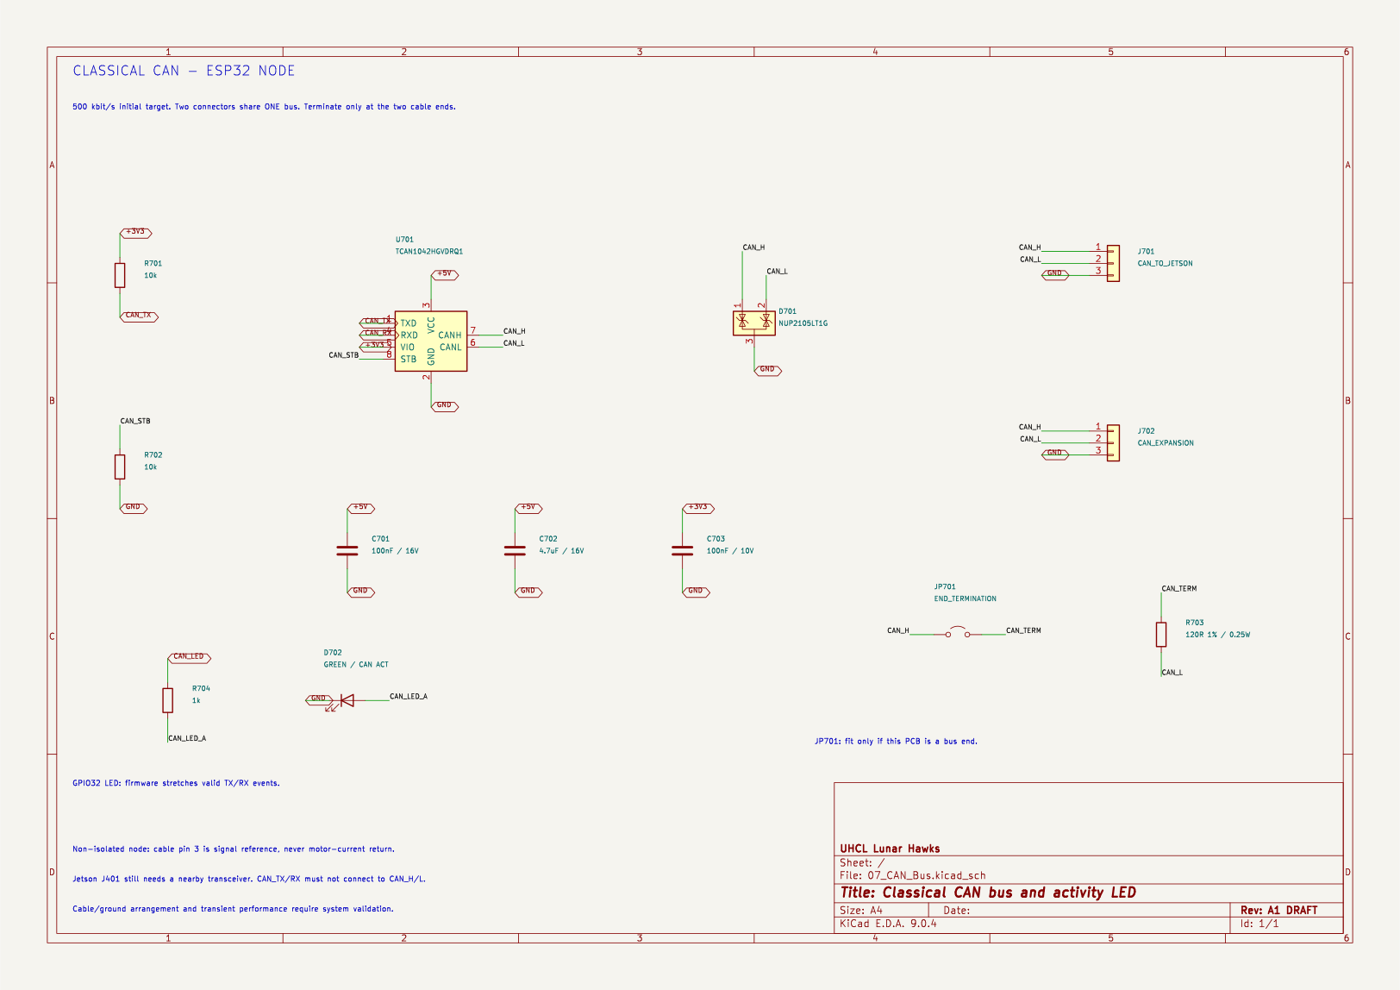
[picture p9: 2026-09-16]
hardware/rover_control_pcb/images/schematic/CAN_Bus_Preview.png

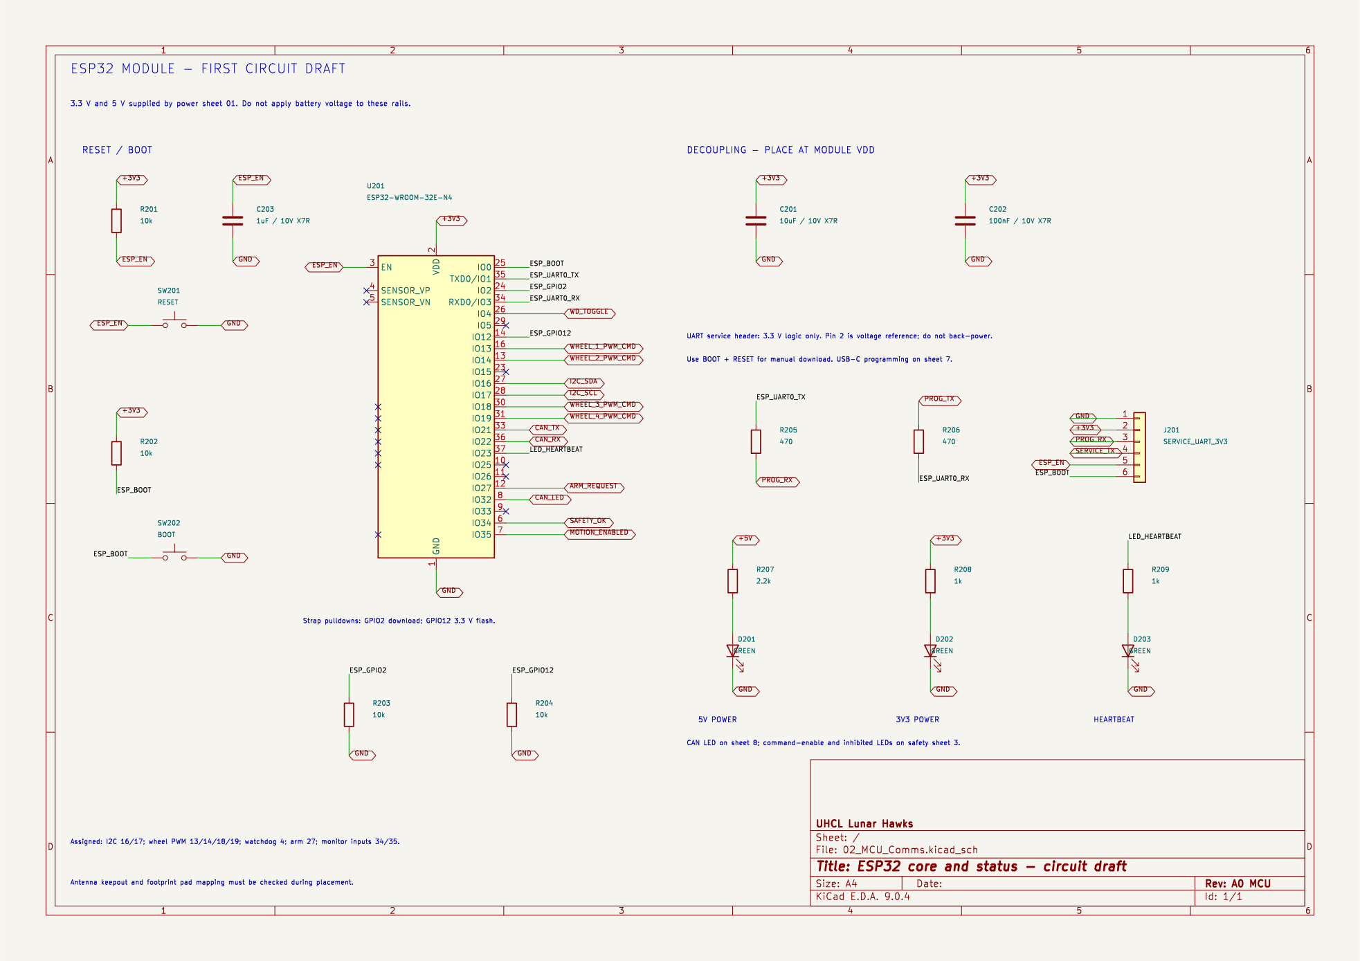
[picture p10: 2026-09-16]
hardware/rover_control_pcb/images/schematic/ESP32_Core_Preview.png

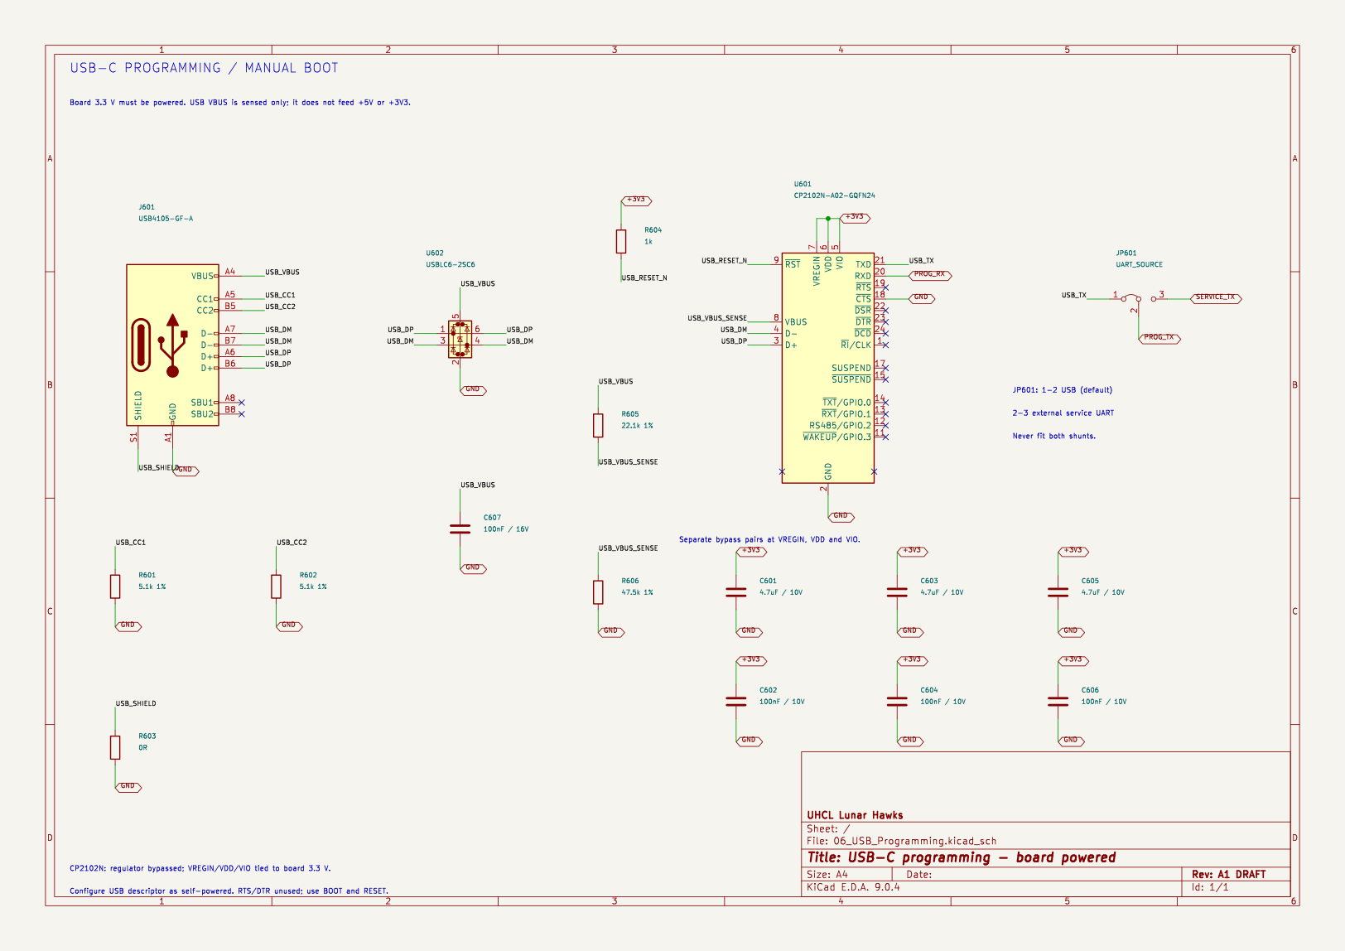
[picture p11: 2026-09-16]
hardware/rover_control_pcb/images/schematic/USB_Programming_Preview.png

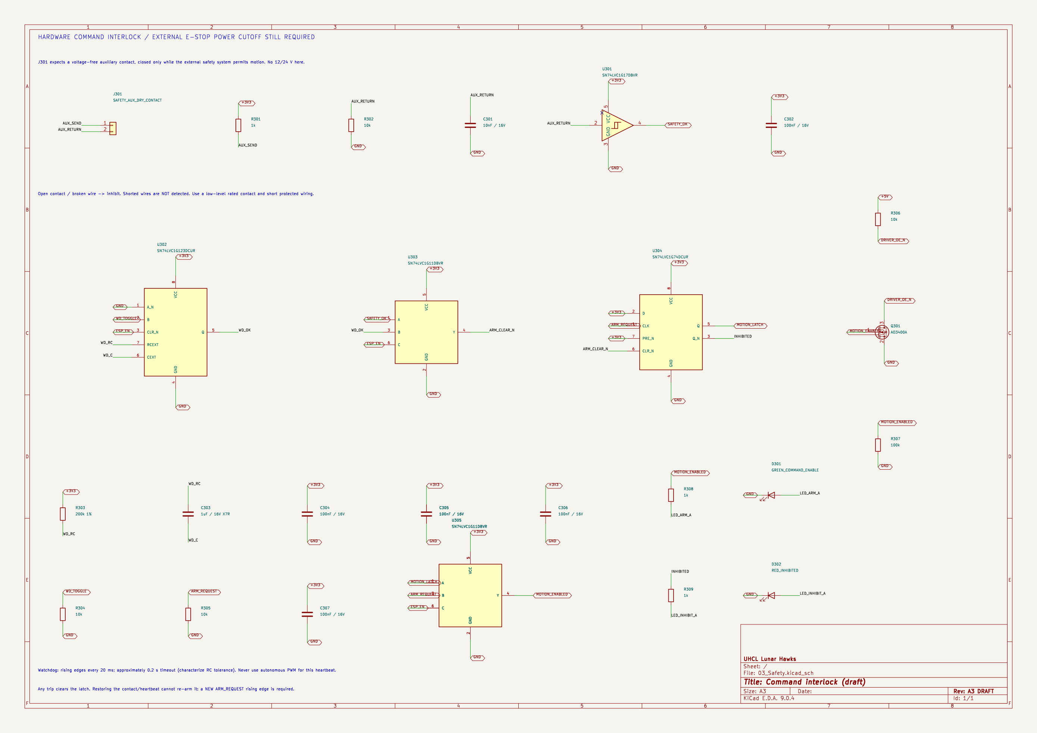
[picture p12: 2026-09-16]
hardware/rover_control_pcb/images/schematic/Safety_Interlock_Preview.png

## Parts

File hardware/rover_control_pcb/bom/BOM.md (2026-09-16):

# Lunar Hawks controller PCB — draft bill of materials

**Status: engineering draft; not released for procurement or assembly.**

Per board: **201 schematic components; 186 populated, 15 DNP.** Quantities do not include purchasing spares. Four board-only mounting holes are mechanical features, not electronic parts.

Generated from a fresh KiCad schematic netlist. References, values, and DNP status were checked against the current PCB. A specified part number is copied from the design, not a claim of stock availability or completed package validation.

## Assembly BOM

| Qty per board | Populate qty | References | Value / function | Specified part number | Footprint | Status |
| ---: | ---: | --- | --- | --- | --- | --- |
| 1 | 1 | C101 | 22uF / 63V | TBD | Capacitor_THT:CP_Radial_D8.0mm_P3.50mm | Populate; Exact ordering code not selected |
| 1 | 1 | C102 | 2.2uF / 100V X7R | TBD | Capacitor_SMD:C_1210_3225Metric | Populate; Exact ordering code not selected |
| 1 | 1 | C103 | 220nF / 100V X7R | TBD | Capacitor_SMD:C_0805_2012Metric | Populate; Exact ordering code not selected |
| 1 | 1 | C104 | 1uF / 10V | TBD | Capacitor_SMD:C_0805_2012Metric | Populate; Exact ordering code not selected |
| 1 | 1 | C105 | 100nF / 16V | TBD | Capacitor_SMD:C_0805_2012Metric | Populate; Exact ordering code not selected |
| 2 | 2 | C106, C107 | 22uF / 25V X7R | TBD | Capacitor_SMD:C_1210_3225Metric | Populate; Exact ordering code not selected |
| 1 | 1 | C108 | 10uF / 16V X7R | TBD | Capacitor_SMD:C_0805_2012Metric | Populate; Exact ordering code not selected |
| 1 | 1 | C109 | 22uF / 16V X7R | TBD | Capacitor_SMD:C_1206_3216Metric | Populate; Exact ordering code not selected |
| 1 | 1 | C201 | 10uF / 10V X7R | TBD | Capacitor_SMD:C_0805_2012Metric | Populate; Exact ordering code not selected |
| 1 | 1 | C202 | 100nF / 10V X7R | TBD | Capacitor_SMD:C_0603_1608Metric | Populate; Exact ordering code not selected |
| 1 | 1 | C203 | 1uF / 10V X7R | TBD | Capacitor_SMD:C_0603_1608Metric | Populate; Exact ordering code not selected |
| 1 | 1 | C301 | 10nF / 16V | TBD | Capacitor_SMD:C_0603_1608Metric | Populate; Exact ordering code not selected |
| 11 | 11 | C302, C304, C305, C306, C307, C401, C403, C404, C405, C607, C701 | 100nF / 16V | TBD | Capacitor_SMD:C_0603_1608Metric | Populate; Exact ordering code not selected |
| 1 | 1 | C303 | 1uF / 16V X7R | TBD | Capacitor_SMD:C_0603_1608Metric | Populate; Exact ordering code not selected |
| 1 | 1 | C402 | 4.7uF / 10V | TBD | Capacitor_SMD:C_0603_1608Metric | Populate; Exact ordering code not selected |
| 3 | 3 | C601, C603, C605 | 4.7uF / 10V | TBD | Capacitor_SMD:C_0805_2012Metric | Populate; Exact ordering code not selected |
| 4 | 4 | C602, C604, C606, C703 | 100nF / 10V | TBD | Capacitor_SMD:C_0603_1608Metric | Populate; Exact ordering code not selected |
| 1 | 1 | C702 | 4.7uF / 16V | TBD | Capacitor_SMD:C_0805_2012Metric | Populate; Exact ordering code not selected |
| 1 | 1 | D101 | STPS1H100A | STPS1H100A | Diode_SMD:D_SMA | Populate; Verify ordering code and package |
| 1 | 1 | D102 | SMBJ33A | SMBJ33A | Diode_SMD:D_SMB | Populate; Verify ordering code and package |
| 3 | 3 | D201, D202, D203 | GREEN | TBD | LED_SMD:LED_0603_1608Metric | Populate; Exact ordering code not selected |
| 1 | 1 | D301 | GREEN_COMMAND_ENABLE | TBD | LED_SMD:LED_0603_1608Metric | Populate; Exact ordering code not selected |
| 1 | 1 | D302 | RED_INHIBITED | TBD | LED_SMD:LED_0603_1608Metric | Populate; Exact ordering code not selected |
| 1 | 1 | D701 | NUP2105LT1G | NUP2105LT1G | Package_TO_SOT_SMD:SOT-23 | Populate; Verify ordering code and package |
| 1 | 1 | D702 | GREEN / CAN ACT | TBD | LED_SMD:LED_0603_1608Metric | Populate; Exact ordering code not selected |
| 1 | 1 | J101 | FUSED_LOGIC_INPUT | TBD | TerminalBlock_Phoenix:TerminalBlock_Phoenix_MKDS-1,5-2_1x02_P5.00mm_Horizontal | Populate; Exact ordering code not selected |
| 1 | 1 | J201 | SERVICE_UART_3V3 | TBD | Connector_PinHeader_2.54mm:PinHeader_1x06_P2.54mm_Vertical | Populate; Exact ordering code not selected |
| 1 | 1 | J301 | SAFETY_AUX_DRY_CONTACT | TBD | TerminalBlock_Phoenix:TerminalBlock_Phoenix_MKDS-1,5-2_1x02_P5.00mm_Horizontal | Populate; Exact ordering code not selected |
| 1 | 1 | J401 | DUMP_1 | TBD | Connector_PinHeader_2.54mm:PinHeader_1x03_P2.54mm_Vertical | Populate; Exact ordering code not selected |
| 1 | 1 | J402 | DUMP_2 | TBD | Connector_PinHeader_2.54mm:PinHeader_1x03_P2.54mm_Vertical | Populate; Exact ordering code not selected |
| 1 | 1 | J403 | DEPLOY_1 | TBD | Connector_PinHeader_2.54mm:PinHeader_1x03_P2.54mm_Vertical | Populate; Exact ordering code not selected |
| 1 | 1 | J404 | DEPLOY_2 | TBD | Connector_PinHeader_2.54mm:PinHeader_1x03_P2.54mm_Vertical | Populate; Exact ordering code not selected |
| 1 | 1 | J405 | EXCAVATOR | TBD | Connector_PinHeader_2.54mm:PinHeader_1x04_P2.54mm_Vertical | Populate; Exact ordering code not selected |
| 1 | 1 | J406 | WHEEL_1 | TBD | Connector_PinHeader_2.54mm:PinHeader_1x03_P2.54mm_Vertical | Populate; Exact ordering code not selected |
| 1 | 1 | J407 | WHEEL_2 | TBD | Connector_PinHeader_2.54mm:PinHeader_1x03_P2.54mm_Vertical | Populate; Exact ordering code not selected |
| 1 | 1 | J408 | WHEEL_3 | TBD | Connector_PinHeader_2.54mm:PinHeader_1x03_P2.54mm_Vertical | Populate; Exact ordering code not selected |
| 1 | 1 | J409 | WHEEL_4 | TBD | Connector_PinHeader_2.54mm:PinHeader_1x03_P2.54mm_Vertical | Populate; Exact ordering code not selected |
| 1 | 1 | J601 | USB4105-GF-A | USB4105-GF-A | Connector_USB:USB_C_Receptacle_GCT_USB4105-xx-A_16P_TopMnt_Horizontal | Populate; Verify ordering code and package |
| 1 | 1 | J701 | CAN_TO_JETSON | TBD | Connector_Molex:Molex_Micro-Fit_3.0_43650-0300_1x03_P3.00mm_Horizontal | Populate; Exact ordering code not selected |
| 1 | 1 | J702 | CAN_EXPANSION | TBD | Connector_Molex:Molex_Micro-Fit_3.0_43650-0300_1x03_P3.00mm_Horizontal | Populate; Exact ordering code not selected |
| 1 | 1 | J801 | WHEEL_1_STOP | TBD | Connector_PinHeader_2.54mm:PinHeader_1x03_P2.54mm_Vertical | Populate; Exact ordering code not selected |
| 1 | 1 | J802 | WHEEL_2_STOP | TBD | Connector_PinHeader_2.54mm:PinHeader_1x03_P2.54mm_Vertical | Populate; Exact ordering code not selected |
| 1 | 1 | J803 | WHEEL_3_STOP | TBD | Connector_PinHeader_2.54mm:PinHeader_1x03_P2.54mm_Vertical | Populate; Exact ordering code not selected |
| 1 | 1 | J804 | WHEEL_4_STOP | TBD | Connector_PinHeader_2.54mm:PinHeader_1x03_P2.54mm_Vertical | Populate; Exact ordering code not selected |
| 1 | 1 | JP601 | UART_SOURCE | TBD | Connector_PinHeader_2.54mm:PinHeader_1x03_P2.54mm_Vertical | Populate; Exact ordering code not selected |
| 1 | 1 | JP701 | END_TERMINATION | TBD | Connector_PinHeader_2.54mm:PinHeader_1x02_P2.54mm_Vertical | Populate; Exact ordering code not selected |
| 1 | 1 | L101 | 22uH / SRN6045TA-220M | SRN6045TA-220M | Inductor_SMD:L_Bourns_SRN6045TA | Populate; Verify ordering code and package |
| 1 | 1 | L102 | 3.3uH / SRN6045TA-3R3Y | SRN6045TA-3R3Y | Inductor_SMD:L_Bourns_SRN6045TA | Populate; Verify ordering code and package |
| 10 | 10 | Q301, Q401, Q402, Q403, Q404, Q801, Q802, Q803, Q804, Q805 | AO3400A | AO3400A | Package_TO_SOT_SMD:SOT-23 | Populate; Verify ordering code and package |
| 2 | 2 | R101, R104 | 100k 1% | TBD | Resistor_SMD:R_0603_1608Metric | Populate; Exact ordering code not selected |
| 1 | 1 | R102 | 24.9k 1% | TBD | Resistor_SMD:R_0603_1608Metric | Populate; Exact ordering code not selected |
| 1 | 1 | R103 | 312k 1% | TBD | Resistor_SMD:R_0603_1608Metric | Populate; Exact ordering code not selected |
| 48 | 48 | R201, R202, R203, R204, R302, R304, R305, R306, R410, R412, R413, R415, R416, R418, R419, R421, R422, R424, R425, R427, R428, R430, R431, R433, R434, R436, R437, R439, R440, R442, R443, R445, R446, R448, R449, R451, R452, R454, R455, R457, R458, R460, R461, R463, R464, R466, R701, R702 | 10k | TBD | Resistor_SMD:R_0603_1608Metric | Populate; Exact ordering code not selected |
| 2 | 2 | R205, R206 | 470 | TBD | Resistor_SMD:R_0603_1608Metric | Populate; Exact ordering code not selected |
| 1 | 1 | R207 | 2.2k | TBD | Resistor_SMD:R_0603_1608Metric | Populate; Exact ordering code not selected |
| 7 | 7 | R208, R209, R301, R308, R309, R604, R704 | 1k | TBD | Resistor_SMD:R_0603_1608Metric | Populate; Exact ordering code not selected |
| 1 | 1 | R303 | 200k 1% | TBD | Resistor_SMD:R_0603_1608Metric | Populate; Exact ordering code not selected |
| 2 | 2 | R307, R805 | 100k | TBD | Resistor_SMD:R_0603_1608Metric | Populate; Exact ordering code not selected |
| 2 | 2 | R401, R402 | 4.7k | TBD | Resistor_SMD:R_0603_1608Metric | Populate; Exact ordering code not selected |
| 8 | 8 | R411, R414, R417, R420, R423, R426, R429, R432 | 220R | TBD | Resistor_SMD:R_0603_1608Metric | Populate; Exact ordering code not selected |
| 2 | 2 | R601, R602 | 5.1k 1% | TBD | Resistor_SMD:R_0603_1608Metric | Populate; Exact ordering code not selected |
| 1 | 1 | R603 | 0R | TBD | Resistor_SMD:R_0603_1608Metric | Populate; Exact ordering code not selected |
| 1 | 1 | R605 | 22.1k 1% | TBD | Resistor_SMD:R_0603_1608Metric | Populate; Exact ordering code not selected |
| 1 | 1 | R606 | 47.5k 1% | TBD | Resistor_SMD:R_0603_1608Metric | Populate; Exact ordering code not selected |
| 1 | 1 | R703 | 120R 1% / 0.25W | TBD | Resistor_SMD:R_1206_3216Metric | Populate; Exact ordering code not selected |
| 4 | 4 | R801, R802, R803, R804 | 680R 1% | TBD | Resistor_SMD:R_0603_1608Metric | Populate; Exact ordering code not selected |
| 4 | 4 | R811, R812, R813, R814 | 47k 1% | TBD | Resistor_SMD:R_0603_1608Metric | Populate; Exact ordering code not selected |
| 1 | 1 | SW201 | RESET | TBD | Button_Switch_SMD:SW_SPST_TL3342 | Populate; Exact ordering code not selected |
| 1 | 1 | SW202 | BOOT | TBD | Button_Switch_SMD:SW_SPST_TL3342 | Populate; Exact ordering code not selected |
| 1 | 1 | U101 | LMR36510ADDAR | LMR36510ADDAR | Package_SO:Texas_HTSOP-8-1EP_3.9x4.9mm_P1.27mm_EP2.95x4.9mm_Mask2.4x3.1mm_ThermalVias | Populate; Verify ordering code and package |
| 1 | 1 | U102 | TPS62160DGKR | TPS62160DGKR | Package_SO:MSOP-8_3x3mm_P0.65mm | Populate; Verify ordering code and package |
| 1 | 1 | U201 | ESP32-WROOM-32E-N4 | ESP32-WROOM-32E-N4 | RF_Module:ESP32-WROOM-32D | Populate; Verify ordering code and package |
| 1 | 1 | U301 | SN74LVC1G17DBVR | SN74LVC1G17DBVR | Package_TO_SOT_SMD:SOT-23-5 | Populate; Verify ordering code and package |
| 1 | 1 | U302 | SN74LVC1G123DCUR | SN74LVC1G123DCUR | Package_SO:VSSOP-8_2.3x2mm_P0.5mm | Populate; Verify ordering code and package |
| 2 | 2 | U303, U305 | SN74LVC1G11DBVR | SN74LVC1G11DBVR | Package_TO_SOT_SMD:SOT-23-6 | Populate; Verify ordering code and package |
| 1 | 1 | U304 | SN74LVC1G74DCUR | SN74LVC1G74DCUR | Package_SO:VSSOP-8_2.3x2mm_P0.5mm | Populate; Verify ordering code and package |
| 1 | 1 | U401 | PCA9685PW | PCA9685PW | Package_SO:TSSOP-28_4.4x9.7mm_P0.65mm | Populate; Verify ordering code and package |
| 3 | 3 | U402, U403, U404 | SN74AHCT244PWR | SN74AHCT244PWR | Package_SO:TSSOP-20_4.4x6.5mm_P0.65mm | Populate; Verify ordering code and package |
| 1 | 1 | U601 | CP2102N-A02-GQFN24 | CP2102N-A02-GQFN24 | Package_DFN_QFN:QFN-24-1EP_4x4mm_P0.5mm_EP2.6x2.6mm | Populate; Verify ordering code and package |
| 1 | 1 | U602 | USBLC6-2SC6 | USBLC6-2SC6 | Package_TO_SOT_SMD:SOT-23-6 | Populate; Verify ordering code and package |
| 1 | 1 | U701 | TCAN1042HGVDRQ1 | TCAN1042HGVDRQ1 | Package_SO:SOIC-8_3.9x4.9mm_P1.27mm | Populate; Verify ordering code and package |
| 4 | 4 | U801, U802, U803, U804 | LTV-817S-B | LTV-817S-B | Package_DIP:SMDIP-4_W9.53mm | Populate; Verify ordering code and package |
| 11 | 0 | R435, R438, R441, R444, R447, R450, R453, R456, R459, R462, R465 | 220R DNP | TBD | Resistor_SMD:R_0603_1608Metric | DNP; Exact ordering code not selected |
| 4 | 0 | R821, R822, R823, R824 | 0R DNP | TBD | Resistor_SMD:R_0603_1608Metric | DNP; Exact ordering code not selected |

## Items to resolve before ordering

- Generic resistors, capacitors, LEDs, headers, and switches need exact manufacturer ordering codes. Confirm voltage, power, tolerance, dielectric, temperature, and mechanical ratings against circuit requirements; unspecified ratings are not implied by a footprint.
- U201 specifies ESP32-WROOM-32E-N4 but uses the library footprint named ESP32-WROOM-32D. Its pad geometry must be checked against the selected module land pattern. The corrected 3D model alone does not validate the footprint.
- Keep all 15 DNP links unpopulated until their associated external driver interfaces have been qualified. Their BOM population quantity is zero.
- Mating cable housings, crimp terminals, jumper shunts, mounting screws/standoffs, the bare PCB, and assembly consumables are not counted above. Select these after connector and enclosure review.

## External rover equipment — excluded from PCB assembly quantities

| Quantity | Equipment | Basis / unresolved detail |
| ---: | --- | --- |
| 4 | ZS-X11H BLDC driver modules | User-supplied equipment; external to controller PCB |
| 4 | DRV8871 actuator driver modules | One per linear actuator; exact module variant to verify |
| 1 | RANSANX excavator driver module | User-described dual H-bridge; exact module identity and ratings to verify |
| 5 | DROK buck converter modules | External motor/actuator supplies; separate from PCB regulators |
| 4 | BLDC wheel motors | Verify whether all match the linked STEPperONLINE motor |
| 4 | 12 V linear actuators | Two dump, two excavator deployment; exact models pending |
| 1 | 12 V excavator motor | Exact model pending |
| 1 | Jetson Orin NX 16 GB with Seeed J401 carrier | User-supplied computer; Jetson-side CAN transceiver still needs selection |
| 1 | Talentcell 25.6 V, 6 Ah LiFePO4 battery | Exact model/BMS ratings pending |
| 1 | Separate V-mount battery for Jetson | Verify exact D-Tap output specification |
| 1 each | DC meter, fusebox, E-stop | Exact meter/fuse selections and E-stop DC interruption rating unresolved |

## Source files

- `Lunar_Hawks_Rover_Control.kicad_sch` and its child sheets.
- `Lunar_Hawks_Rover_Control.kicad_pcb` for population cross-check.
- `BOM_Components.json` contains one record per schematic component for machine-readable use.

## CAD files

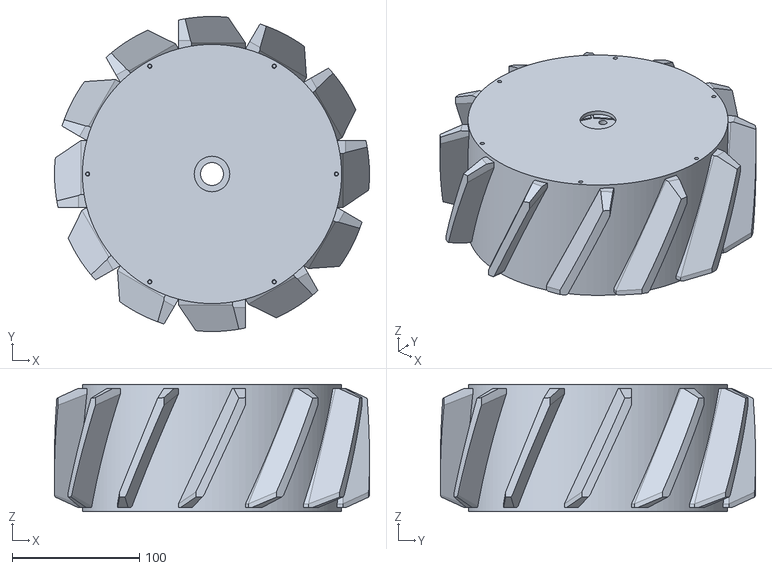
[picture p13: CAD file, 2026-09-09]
cad/full_rover/wheel_assembled.stl
248.0 x 248.0 x 100.0

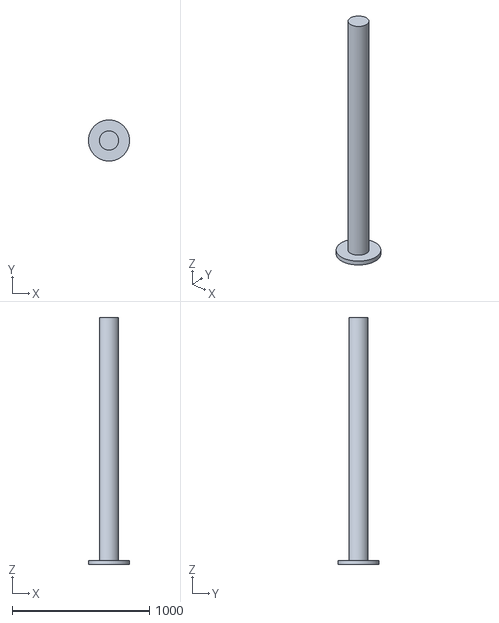
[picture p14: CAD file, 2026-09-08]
cad/autonomy_rover/goal_post.stl
300.0 x 300.0 x 1800.0

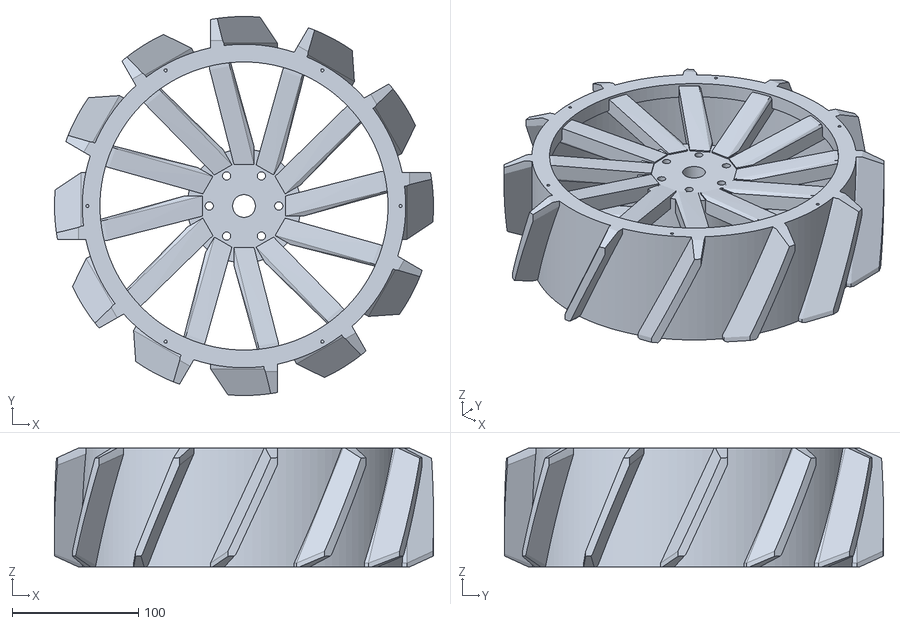
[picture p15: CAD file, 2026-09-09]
cad/full_rover/wheel_300mm_lab_body_for_covers.stl
300.0 x 300.0 x 94.0

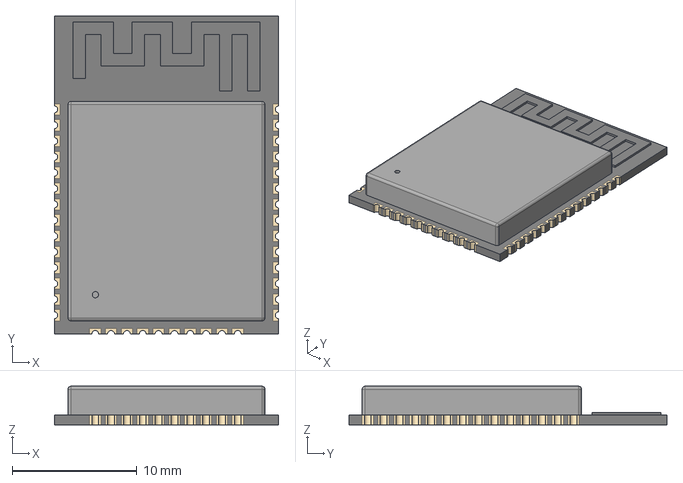
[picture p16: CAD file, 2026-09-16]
hardware/rover_control_pcb/3dmodels/ESP32-WROOM-32E.step
18.0 x 25.5 x 3.10 mm

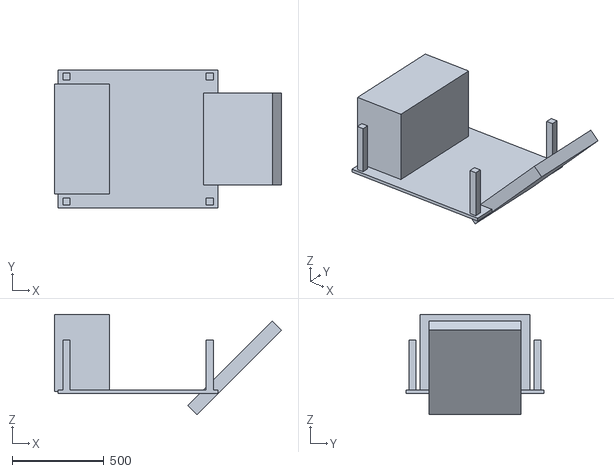
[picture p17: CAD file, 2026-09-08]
cad/autonomy_rover/rover_chassis_simplified.stl
1234.6 x 750.0 x 544.6

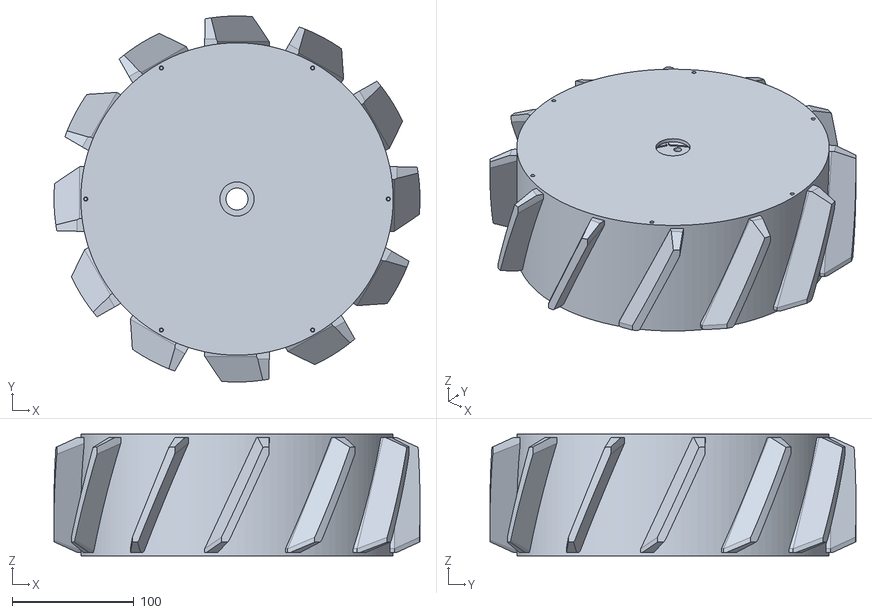
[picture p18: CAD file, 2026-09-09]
cad/full_rover/wheel_300mm_lab_covered.stl
300.0 x 300.0 x 100.0

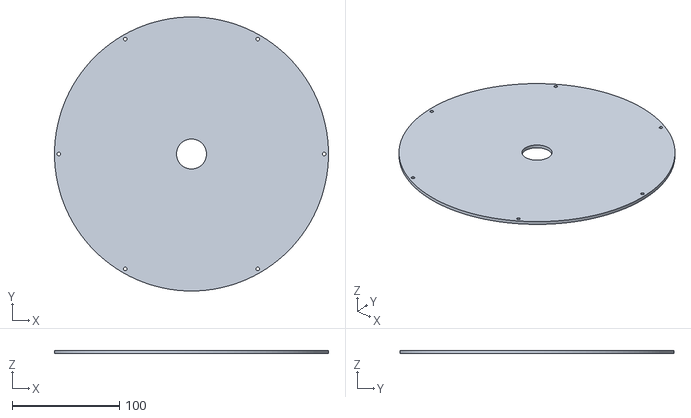
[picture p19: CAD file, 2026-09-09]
cad/wheel_300mm_lab_cover.stl
256.0 x 256.0 x 3.00

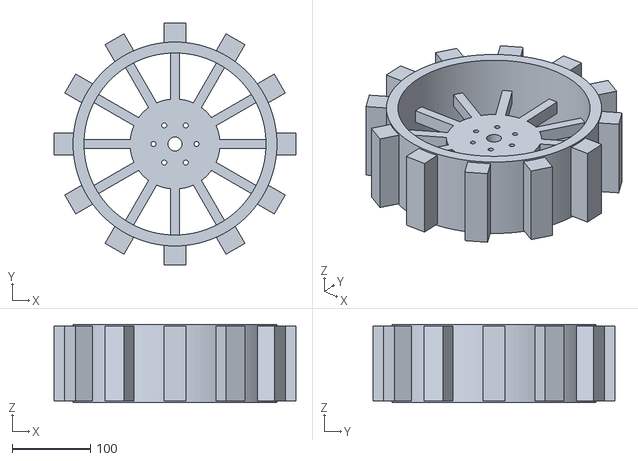
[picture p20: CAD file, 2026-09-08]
cad/autonomy_rover/grouser_wheel_12_short.stl
309.5 x 309.5 x 100.0

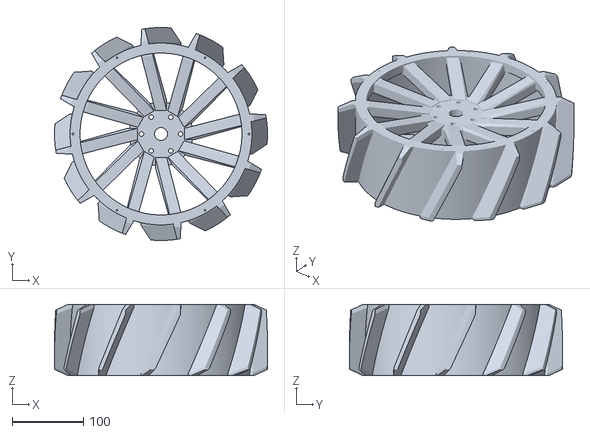
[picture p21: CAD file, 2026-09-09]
cad/full_rover/wheel_300mm_lab.stl
300.0 x 300.0 x 100.0

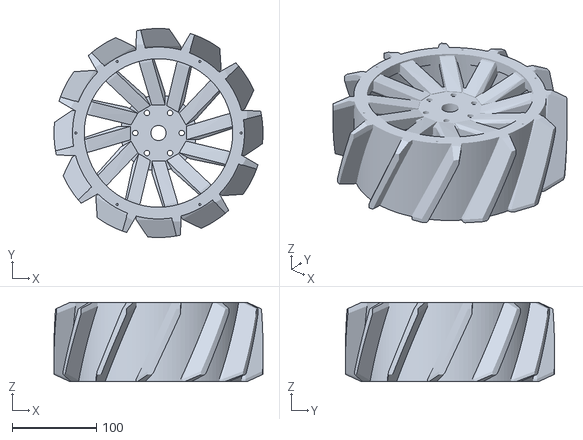
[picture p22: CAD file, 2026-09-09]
cad/wheel.stl
248.0 x 248.0 x 94.0

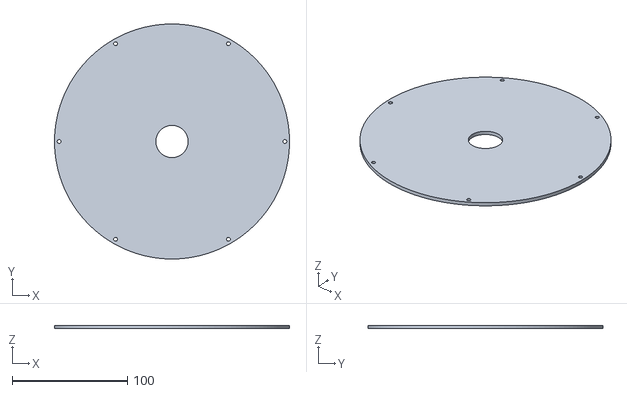
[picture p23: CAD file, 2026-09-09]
cad/full_rover/wheel_cover.stl
204.0 x 204.0 x 3.00

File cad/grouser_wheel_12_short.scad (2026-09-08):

// UHCL NASA Lunabotics grouser wheel — parametric test article
// Paper dimensions: 304.8 mm diameter, 100 mm width, 12 evenly spaced grousers.
// Requested change: radial grouser projection shortened to ~half of the prior nominal fin length.
$fn=128;
wheel_d=304.8;
wheel_w=100;
rim_t=14;
hub_d=115;
hub_t=16;
num_grousers=12;
grouser_radial=22; // shortened; baseline parametric fin was 44 mm
grouser_tangential=28;
grouser_axial=96;
shaft_hole=18;
bolt_circle=55;
bolt_d=6.5;
module wheel(){
 difference(){
  union(){
   difference(){ cylinder(d=wheel_d-2*grouser_radial,h=wheel_w,center=true); cylinder(d=wheel_d-2*grouser_radial-2*rim_t,h=wheel_w+2,center=true); }
   cylinder(d=hub_d,h=hub_t,center=true);
   for(a=[0:360/num_grousers:359]) rotate([0,0,a]) translate([(wheel_d/2-grouser_radial/2-rim_t/3),0,0]) cube([grouser_radial+rim_t,grouser_tangential,grouser_axial],center=true);
   for(a=[0:30:330]) rotate([0,0,a]) hull(){ translate([hub_d/2-5,0,0]) cylinder(d=12,h=hub_t,center=true); translate([wheel_d/2-grouser_radial-rim_t/2,0,0]) cylinder(d=12,h=hub_t,center=true); }
  }
  cylinder(d=shaft_hole,h=wheel_w+5,center=true);
  for(a=[0:60:359]) rotate([0,0,a]) translate([bolt_circle/2,0,0]) cylinder(d=bolt_d,h=wheel_w+5,center=true);
 }
}
wheel();

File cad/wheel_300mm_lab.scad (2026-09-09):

// UHCL Lunar Hawks 300 mm laboratory-printer wheel test article.
// Outside diameter: 300 mm; axial width: 100 mm.
// Twelve swept fins at 30 degree spacing with 22 mm radial projection.
// Open-face configuration: optional side covers are intentionally omitted.
// Hub bore and bolt pattern remain provisional and must be checked on the rover.

use <wheel_open_spoke.scad>

part = "open";

// The open test article is 100 mm wide as a single printable body.
if (part == "open")
    wheel_body(outer_d=300, width=100, fin_height=22);

// The covered assembly uses a 94 mm body plus two 3 mm covers.
if (part == "body_for_covers")
    wheel_body(outer_d=300, width=94, fin_height=22);

if (part == "cover")
    wheel_cover(outer_d=300, fin_height=22);

if (part == "covered")
    assembled_reference_wheel(outer_d=300, width=100, fin_height=22);

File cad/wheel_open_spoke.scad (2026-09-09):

// Photo-derived open-spoke wheel, dimensions in mm. Provisional hub interfaces.
// 248 mm OD fits nominal 256 mm bed with 4 mm margin per side.
// Twelve swept, tapered fins. 22 mm radial projection retains the earlier half-fin request.
module wheel_body(outer_d=248, width=94, fin_height=22) {
 rim_r=outer_d/2-fin_height;
 difference() {
  union() {
   // 8 mm continuous tread band plus reinforced edge rings; no solid side disks.
   difference() { cylinder(r=rim_r,h=width,center=true,$fn=120);
                  cylinder(r=rim_r-8,h=width+2,center=true,$fn=120); }
   for(z=[-width/2+6,width/2-6]) translate([0,0,z])
    difference() { cylinder(r=rim_r,h=12,center=true,$fn=120);
                   cylinder(r=rim_r-14,h=14,center=true,$fn=120); }
   cylinder(r=45,h=64,center=true,$fn=96);
   // Twelve thick swept spokes on each side, leaving the web open.
   for(z=[-1,1]) for(i=[0:11]) rotate([0,0,i*30]) hull() {
    translate([40,0,z*27]) cube([14,16,12],center=true);
    rotate([0,0,10]) translate([rim_r-9,0,z*(width/2-8)]) cube([16,16,12],center=true);
   }
   // Thick angled paddles: diagonal across the width, tapered at the shoulders.
   // Envelope clipping keeps the fin-tip outside diameter exactly outer_d.
   intersection() {
    cylinder(d=outer_d,h=width,center=true,$fn=240);
    union() for(i=[0:11]) rotate([0,0,i*30]) hull() {
     for(z=[-width/2+1,width/2-1])
      translate([rim_r-3,tan(25)*z,z]) cube([8,10,4],center=true);
     for(z=[-width/2+12,width/2-12])
      translate([outer_d/2+1,8+tan(25)*z,z]) cube([4,4,4],center=true);
    }
   }
  }
  // Six blind 2.5 mm pilot holes per face for prototype cover fasteners.
  for(side=[-1,1]) for(i=[0:5]) rotate([0,0,i*60])
   translate([rim_r-4,0,side*(width/2)]) rotate([side==1?180:0,0,0])
    translate([0,0,-1]) cylinder(d=2.5,h=9,$fn=24);
  cylinder(d=18,h=width+4,center=true,$fn=64);
  for(i=[0:5]) rotate([0,0,i*60]) translate([27.5,0,0]) cylinder(d=6.5,h=width+4,center=true,$fn=32);
 }
}

// Same cover is printed twice. All sizes in mm. Central opening is not a dust seal.
module wheel_cover(outer_d=248, fin_height=22) {
 rim_r=outer_d/2-fin_height;
 difference() {
  cylinder(r=rim_r,h=3,$fn=120);
  translate([0,0,-1]) cylinder(d=28,h=5,$fn=64);
  for(i=[0:5]) rotate([0,0,i*60]) translate([rim_r-4,0,-1]) cylinder(d=3.4,h=5,$fn=24);
 }
}
module reference_wheel(outer_d=248,width=100,fin_height=22) {
 wheel_body(outer_d,width-6,fin_height);
}
module assembled_reference_wheel(outer_d=248,width=100,fin_height=22) {
 reference_wheel(outer_d,width,fin_height);
 for(side=[-1,1]) translate([0,0,side*(width/2-3)]) rotate([side==1?0:180,0,0]) wheel_cover(outer_d,fin_height);
}

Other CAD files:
cad/12_inch+Linear+actuator.stl
cad/12mm+Sprocket.stl
cad/Bucket+#1.stl
cad/Door+Frame.stl
cad/Hatch+Design.stl
cad/actuator_body.stl
cad/actuator_rod.stl
cad/autonomy_rover/goal_post.scad
cad/autonomy_rover/rover_chassis_simplified.scad
cad/bucket.stl
cad/chassis.stl
cad/conveyor.stl
cad/esp32_base.stl
cad/esp32_lid.stl
cad/full_rover/actuator_body.stl
cad/full_rover/actuator_rod.stl
cad/full_rover/bucket.stl
cad/full_rover/chassis.stl
cad/full_rover/conveyor.stl
cad/full_rover/esp32_base.stl
cad/full_rover/esp32_lid.stl
cad/full_rover/gate.stl
cad/full_rover/jetson_base.stl
cad/full_rover/jetson_lid.stl
cad/full_rover/latch.stl
cad/full_rover/rover.scad
cad/full_rover/scoop.stl
cad/gate.stl
cad/goal_post.scad
cad/jetson_base.stl
cad/jetson_lid.stl
cad/latch.stl
cad/rover.scad
cad/rover_chassis_simplified.scad
cad/scoop.stl

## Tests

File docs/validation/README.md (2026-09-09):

# Target-environment validation

Verified simulation source: `a8d5f6cc39775b93eef177a1c34e09acdc090bc5`.

[Successful Gazebo/RViz and KiCad run](https://github.com/Matthew-Garcia/NASA-Lunabotics-UHCL-Lunar-Hawks/actions/runs/34300162141).

## Results

- ROS 2 Humble / Gazebo 11: colcon compilation succeeds, Gazebo spawns the rover and RViz starts with software OpenGL under Xvfb.
- Fifteen runtime checks pass: camera/LiDAR/odometry/joint/mechanism messages; initial stow and latch; blocked conveyor while stowed; deploy; moving scoops; conveyor stop; retract; latch blocks tip; release; tip; passive door opening; lower; passive door closure; re-latch; drive displacement.
- The door reached about 0.925 rad while the bucket tipped, then returned below the unchanged 0.04 rad closure threshold through gravity. Bucket SetPosition now preserves descendant world velocities, allowing the passive door to swing. No door motor or forced closure is used.
- KiCad 9.0.9: schematic loads, SVG export succeeds, ERC reports **0 errors and 0 warnings**. Local symbol library and table resolve module symbols. Connector placement uses the electrical grid; dangling USB labels were terminated at sensor ports.
- 24 host tests pass, including seven mission tests with ROS message stubs.

Raw reports: [Gazebo runtime](gazebo-runtime.json), [KiCad ERC](kicad-erc.rpt). Workflow artifacts include runtime logs, screenshots, schematic SVG and compiler logs. Re-run `.github/workflows/validate-rover.yml` to regenerate evidence.

## What these checks do not establish

The probe directly commands mechanisms; it does not run the complete autonomous mission or establish goal detection accuracy, navigation, rock retention, or delivery into the pad. Material pickup and transfer remain scripted. Bucket/lift actuation is kinematic, actuator geometry is illustrative, and wheels use simplified collision cylinders. ROS TF completeness and sensor calibration need further validation.

The schematic is a module-level wiring draft using generic passive connector pins. Clean ERC cannot verify real module pinouts, voltage compatibility, BLDC controller selection, contactor/fuse sizing, grounding, actuator synchronization or production readiness. Original assembly dimensions and enclosure fits remain unverified. No physical hardware was operated.

## Captured views

Both applications were raised separately and inspected. RViz renders the rover; its goal-detection image is blank because the probe leaves the optional autonomy/perception launch disabled.

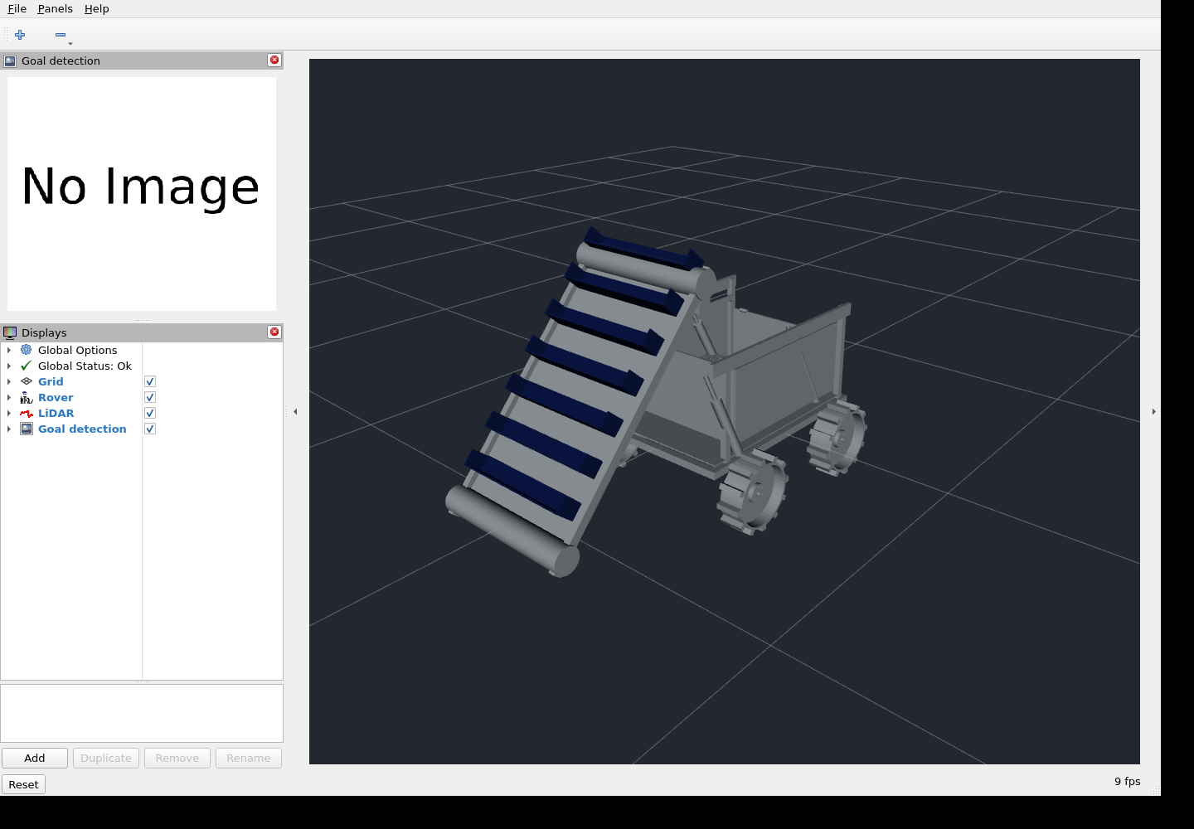
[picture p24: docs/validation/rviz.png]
RViz rover


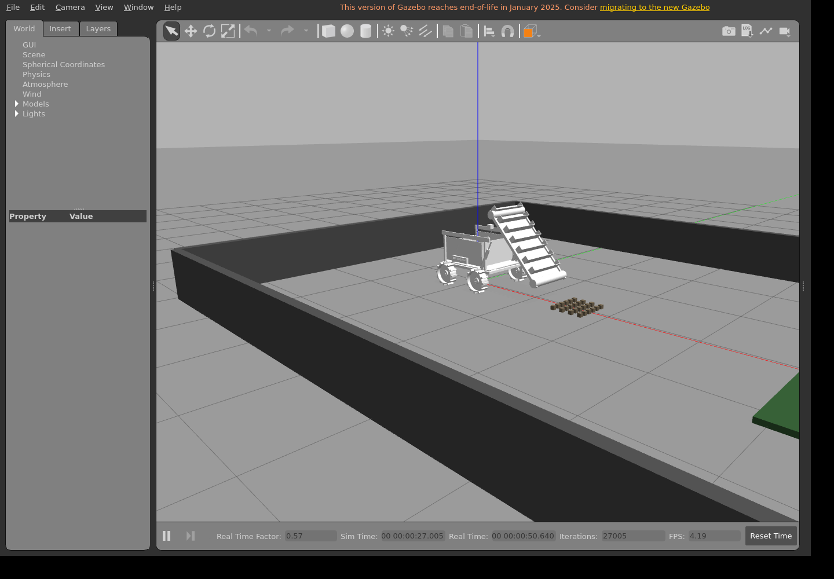
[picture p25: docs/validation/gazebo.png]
Gazebo arena


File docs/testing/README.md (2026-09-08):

# Verification and evidence register

## Host checks

~~~bash
python3 firmware/micropython/test.py
python3 -m unittest discover -s tests -v
python3 -m compileall -q firmware/micropython ros2_ws/src tests
~~~

These check dry-run command handling and a limited WebSocket implementation on CPython. They do not validate ESP32 execution, GPIO, ROS runtime, or physical safety. See VALIDATION.md for migration-time results.

| Feature | Available evidence | Required next validation |
| --- | --- | --- |
| Mobility/turning | Owner-reported demo; rover photo | Dated video, procedure, hardware/software revision |
| Conveyor/material transport | Owner-reported demo | Dated clip, load, duration, result |
| Bucket disposal | Owner-reported demo | Limits, current/load checks, video |
| ROS 2 / micro-ROS | Existing source and historical PDF | Clean build, serial setup, topic recording |
| Simulation | Archived Gazebo video | Model/world/configuration and reproducible launch |
| New MicroPython | Host tests | Target interpreter test; no physical actuation implemented |
| Proposed PCB | Requirements only | ERC, DRC, review, staged electrical tests |

Physical-test log fields: date; operator; hardware revision; commit SHA; conditions/load; instruments; procedure; expected result; actual result; evidence filename; issues; pass/fail. Leave unknown measurements unknown.

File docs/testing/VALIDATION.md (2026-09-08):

# Migration-time validation — 2026-09-08

| Check | Result | Scope |
| --- | --- | --- |
| MicroPython-compatible self-test | PASS | CPython host only |
| unittest discovery | PASS: 14 tests | Command validation/mixing, deadman, timeout, WebSocket handshake/framing/local socket, links and ROS metadata |
| Python compileall | PASS | Python syntax, not ROS imports or MCU compatibility |
| git diff --check | PASS before commit | Whitespace hygiene |
| Original C application / colcon metadata | Byte-identical to source | Preserved, not rebuilt |
| Original software PDF | Byte-identical to source | Historical documentation, not publication manuscript |
| ROS 2 runtime and build | NOT RUN | Target ROS environment unavailable |
| ESP32 / MicroPython target execution | NOT RUN | Hardware unavailable |
| PCB ERC / DRC / electrical test | NOT RUN | Concept documentation only; schematic/layout not designed |

Host checks are also configured in .github/workflows/host-checks.yml. A workflow definition is not proof of a completed GitHub Actions run. This report does not assert physical performance or safe deployment.

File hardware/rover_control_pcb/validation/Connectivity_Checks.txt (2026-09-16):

PASS: 26 net-connectivity checks; USB VBUS/5V/3V3/GND distinct; UART sources separate; CAN H/L distinct; custom CAN pin assignment matches TI; 201 components.
PASS: 12 power-connectivity checks; 12 critical nodes distinct; regulator pin assignments and 20 new physical footprint pad mappings verified.
Divider targets: 5.016 V and 3.296 V. Planning load: 0.643 A on 5 V at 600 mA on 3.3 V plus 150 mA direct 5 V load, assuming 80% second-stage efficiency. Not measured performance.
PASS: 19 independent command paths, including four wheel MOSFET gate/drain/source routes with no rail tie at DIR connectors; 15 PCA channels and 4 direct PWM mappings; I2C/address/enable wiring; 23 interlock net groups; 106 new footprint pad mappings; custom logic pin tables; 11 wheel/excavator links explicitly DNP.
No dynamic circuit simulation or physical stopping/EMC validation performed.
PASS: four driver-powered stop-request channels; common hardware release gate; seven distinct driver/logic/ground rails; 26 additional footprint pad mappings; four STOP links DNP (15 DNP links overall). Physical behavior remains unverified.

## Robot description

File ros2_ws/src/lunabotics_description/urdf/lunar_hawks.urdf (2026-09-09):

<robot name="lunar_hawks">
  <link name="base_link">
    <inertial>
      <mass value="20" />
      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
    </inertial>
    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
  </link>
  <link name="wheel_fl">
    <inertial>
      <mass value="2" />
      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
    </inertial>
    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
  </link>
  <joint name="wheel_fl_joint" type="continuous">
    <parent link="base_link" />
    <child link="wheel_fl" />
    <origin xyz="0.28 0.375 -.1076" rpy="1.57079632679 0 0" />
    <axis xyz="0 0 -1" />
    <dynamics damping="0.4" friction="0.05" />
  </joint>
  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
  <link name="wheel_rl">
    <inertial>
      <mass value="2" />
      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
    </inertial>
    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
  </link>
  <joint name="wheel_rl_joint" type="continuous">
    <parent link="base_link" />
    <child link="wheel_rl" />
    <origin xyz="-0.28 0.375 -.1076" rpy="1.57079632679 0 0" />
    <axis xyz="0 0 -1" />
    <dynamics damping="0.4" friction="0.05" />
  </joint>
  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
  <link name="wheel_fr">
    <inertial>
      <mass value="2" />
      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
    </inertial>
    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
  </link>
  <joint name="wheel_fr_joint" type="continuous">
    <parent link="base_link" />
    <child link="wheel_fr" />
    <origin xyz="0.28 -0.375 -.1076" rpy="1.57079632679 0 0" />
    <axis xyz="0 0 -1" />
    <dynamics damping="0.4" friction="0.05" />
  </joint>
  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
  <link name="wheel_rr">
    <inertial>
      <mass value="2" />
      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
    </inertial>
    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
  </link>
  <joint name="wheel_rr_joint" type="continuous">
    <parent link="base_link" />
    <child link="wheel_rr" />
    <origin xyz="-0.28 -0.375 -.1076" rpy="1.57079632679 0 0" />
    <axis xyz="0 0 -1" />
    <dynamics damping="0.4" friction="0.05" />
  </joint>
  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
  <link name="bucket">
    <inertial>
      <mass value="5" />
      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
    </inertial>
    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
  </link>
  <joint name="bucket_joint" type="revolute">
    <parent link="base_link" />
    <child link="bucket" />
    <origin xyz="-.38 0 .05" rpy="0 0 0" />
    <axis xyz="0 -1 0" />
    <dynamics damping="0.4" friction="0.05" />
    <limit lower="0" upper="1.0" effort="800" velocity="0.2" />
  </joint>
  <link name="rear_door">
    <inertial>
      <mass value="1" />
      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
      <origin xyz="0 0 -.12" />
    </inertial>
    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
  </link>
  <joint name="rear_door_joint" type="revolute">
    <parent link="bucket" />
    <child link="rear_door" />
    <origin xyz="0 0 .24" rpy="0 0 0" />
    <axis xyz="0 1 0" />
    <dynamics damping="0.08" friction="0.002" />
    <limit lower="0" upper="1.6" effort="800" velocity="0.2" />
  </joint>
  <link name="electronic_latch">
    <inertial>
      <mass value="0.1" />
      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
    </inertial>
    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
  </link>
  <joint name="latch_mount" type="fixed">
    <parent link="bucket" />
    <child link="electronic_latch" />
    <origin xyz="-.02 0 .015" rpy="0 0 0" />
  </joint>
  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
  <link name="excavator_pivot">
    <inertial>
      <mass value="0.3" />
      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
    </inertial>
    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
  </link>
  <joint name="excavator_deploy_joint" type="revolute">
    <parent link="base_link" />
    <child link="excavator_pivot" />
    <origin xyz=".424 0 .706" rpy="0 0 0" />
    <axis xyz="0 1 0" />
    <dynamics damping="0.4" friction="0.05" />
    <limit lower="-0.25" upper="0" effort="800" velocity="0.2" />
  </joint>
  <link name="conveyor">
    <inertial>
      <mass value="4" />
      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
    </inertial>
    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
  </link>
  <joint name="conveyor_mount" type="fixed">
    <parent link="excavator_pivot" />
    <child link="conveyor" />
    <origin xyz=".476 0 -.896" rpy="0 -.488692 0" />
  </joint>
  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
  <link name="conveyor_drive">
    <inertial>
      <mass value="0.1" />
      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
    </inertial>
    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
  </link>
  <joint name="conveyor_drive_joint" type="continuous">
    <parent link="conveyor" />
    <child link="conveyor_drive" />
    <origin xyz="0 0 1.005" rpy="0 0 0" />
    <axis xyz="0 1 0" />
    <dynamics damping="0.4" friction="0.05" />
  </joint>
  <link name="scoop_0">
    <inertial>
      <mass value="0.1" />
      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
    </inertial>
    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
  </link>
  <joint name="scoop_0_joint" type="prismatic">
    <parent link="conveyor" />
    <child link="scoop_0" />
    <origin xyz=".012 0 .1" rpy="0 0 0" />
    <axis xyz="0 0 1" />
    <dynamics damping="0.4" friction="0.05" />
    <limit lower="0" upper="0.95" effort="800" velocity="0.2" />
  </joint>
  <link name="scoop_1">
    <inertial>
      <mass value="0.1" />
      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
    </inertial>
    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
  </link>
  <joint name="scoop_1_joint" type="prismatic">
    <parent link="conveyor" />
    <child link="scoop_1" />
    <origin xyz=".012 0 .1" rpy="0 0 0" />
    <axis xyz="0 0 1" />
    <dynamics damping="0.4" friction="0.05" />
    <limit lower="0" upper="0.95" effort="800" velocity="0.2" />
  </joint>
  <link name="scoop_2">
    <inertial>
      <mass value="0.1" />
      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
    </inertial>
    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
  </link>
  <joint name="scoop_2_joint" type="prismatic">
    <parent link="conveyor" />
    <child link="scoop_2" />
    <origin xyz=".012 0 .1" rpy="0 0 0" />
    <axis xyz="0 0 1" />
    <dynamics damping="0.4" friction="0.05" />
    <limit lower="0" upper="0.95" effort="800" velocity="0.2" />
  </joint>
  <link name="scoop_3">
    <inertial>
      <mass value="0.1" />
      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
    </inertial>
    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
  </link>
  <joint name="scoop_3_joint" type="prismatic">
    <parent link="conveyor" />
    <child link="scoop_3" />
    <origin xyz=".012 0 .1" rpy="0 0 0" />
    <axis xyz="0 0 1" />
    <dynamics damping="0.4" friction="0.05" />
    <limit lower="0" upper="0.95" effort="800" velocity="0.2" />
  </joint>
  <link name="scoop_4">
    <inertial>
      <mass value="0.1" />
      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
    </inertial>
    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
  </link>
  <joint name="scoop_4_joint" type="prismatic">
    <parent link="conveyor" />
    <child link="scoop_4" />
    <origin xyz=".012 0 .1" rpy="0 0 0" />
    <axis xyz="0 0 1" />
    <dynamics damping="0.4" friction="0.05" />
    <limit lower="0" upper="0.95" effort="800" velocity="0.2" />
  </joint>
  <link name="scoop_5">
    <inertial>
      <mass value="0.1" />
      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
    </inertial>
    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
  </link>
  <joint name="scoop_5_joint" type="prismatic">
    <parent link="conveyor" />
    <child link="scoop_5" />
    <origin xyz=".012 0 .1" rpy="0 0 0" />
    <axis xyz="0 0 1" />
    <dynamics damping="0.4" friction="0.05" />
    <limit lower="0" upper="0.95" effort="800" velocity="0.2" />
  </joint>
  <link name="scoop_6">
    <inertial>
      <mass value="0.1" />
      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
    </inertial>
    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
  </link>
  <joint name="scoop_6_joint" type="prismatic">
    <parent link="conveyor" />
    <child link="scoop_6" />
    <origin xyz=".012 0 .1" rpy="0 0 0" />
    <axis xyz="0 0 1" />
    <dynamics damping="0.4" friction="0.05" />
    <limit lower="0" upper="0.95" effort="800" velocity="0.2" />
  </joint>
  <link name="esp32">
    <inertial>
      <mass value="0.3" />
      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
    </inertial>
    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
  </link>
  <joint name="esp32_mount" type="fixed">
    <parent link="base_link" />
    <child link="esp32" />
    <origin xyz="0.14 -0.22 .05" rpy="0 0 0" />
  </joint>
  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
  <link name="esp32_lid">
    <inertial>
      <mass value="0.1" />
      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
    </inertial>
    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
  </link>
  <joint name="esp32_lid_mount" type="fixed">
    <parent link="esp32" />
    <child link="esp32_lid" />
    <origin xyz="0 0 .04" rpy="0 0 0" />
  </joint>
  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
  <link name="jetson">
    <inertial>
      <mass value="0.3" />
      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
    </inertial>
    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
  </link>
  <joint name="jetson_mount" type="fixed">
    <parent link="base_link" />
    <child link="jetson" />
    <origin xyz="-0.1 -0.22 .05" rpy="0 0 0" />
  </joint>
  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
  <link name="jetson_lid">
    <inertial>
      <mass value="0.1" />
      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
    </inertial>
    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
  </link>
  <joint name="jetson_lid_mount" type="fixed">
    <parent link="jetson" />
    <child link="jetson_lid" />
    <origin xyz="0 0 .07" rpy="0 0 0" />
  </joint>
  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
  <link name="actuator_left">
    <inertial>
      <mass value="0.7" />
      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
    </inertial>
    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
  </link>
  <joint name="actuator_left_mount" type="fixed">
    <parent link="base_link" />
    <child link="actuator_left" />
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

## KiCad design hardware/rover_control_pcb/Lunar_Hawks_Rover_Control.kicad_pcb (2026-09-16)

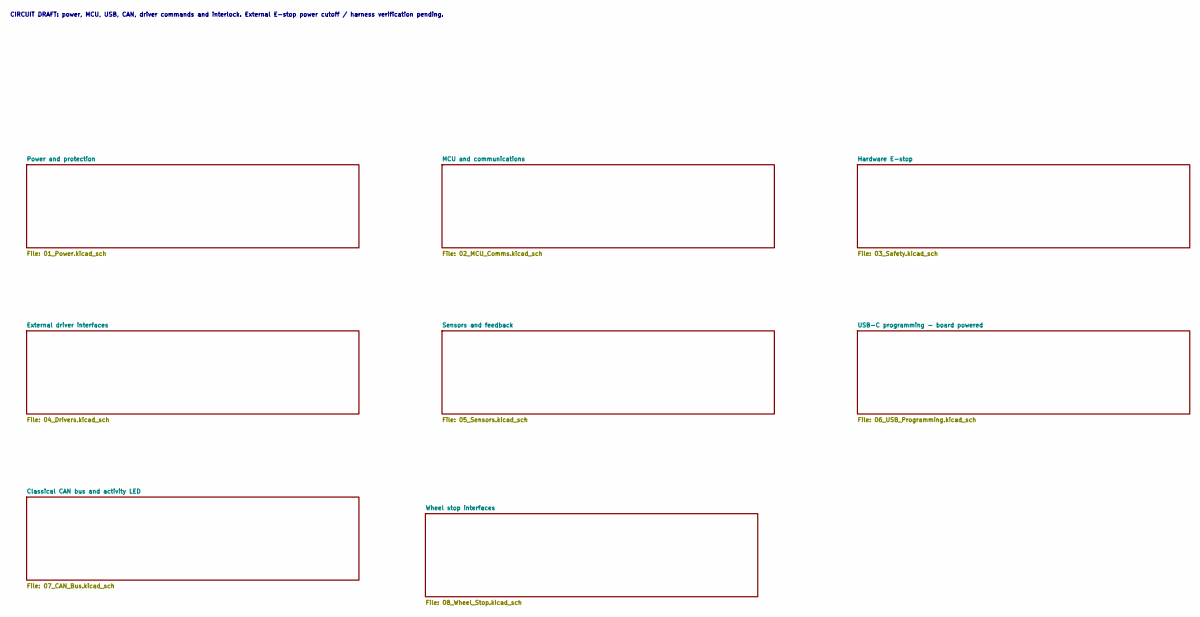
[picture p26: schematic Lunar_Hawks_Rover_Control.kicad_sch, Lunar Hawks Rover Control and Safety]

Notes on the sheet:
CIRCUIT DRAFT: power, MCU, USB, CAN, driver commands and interlock. External E-stop power cutoff / harness verification pending.

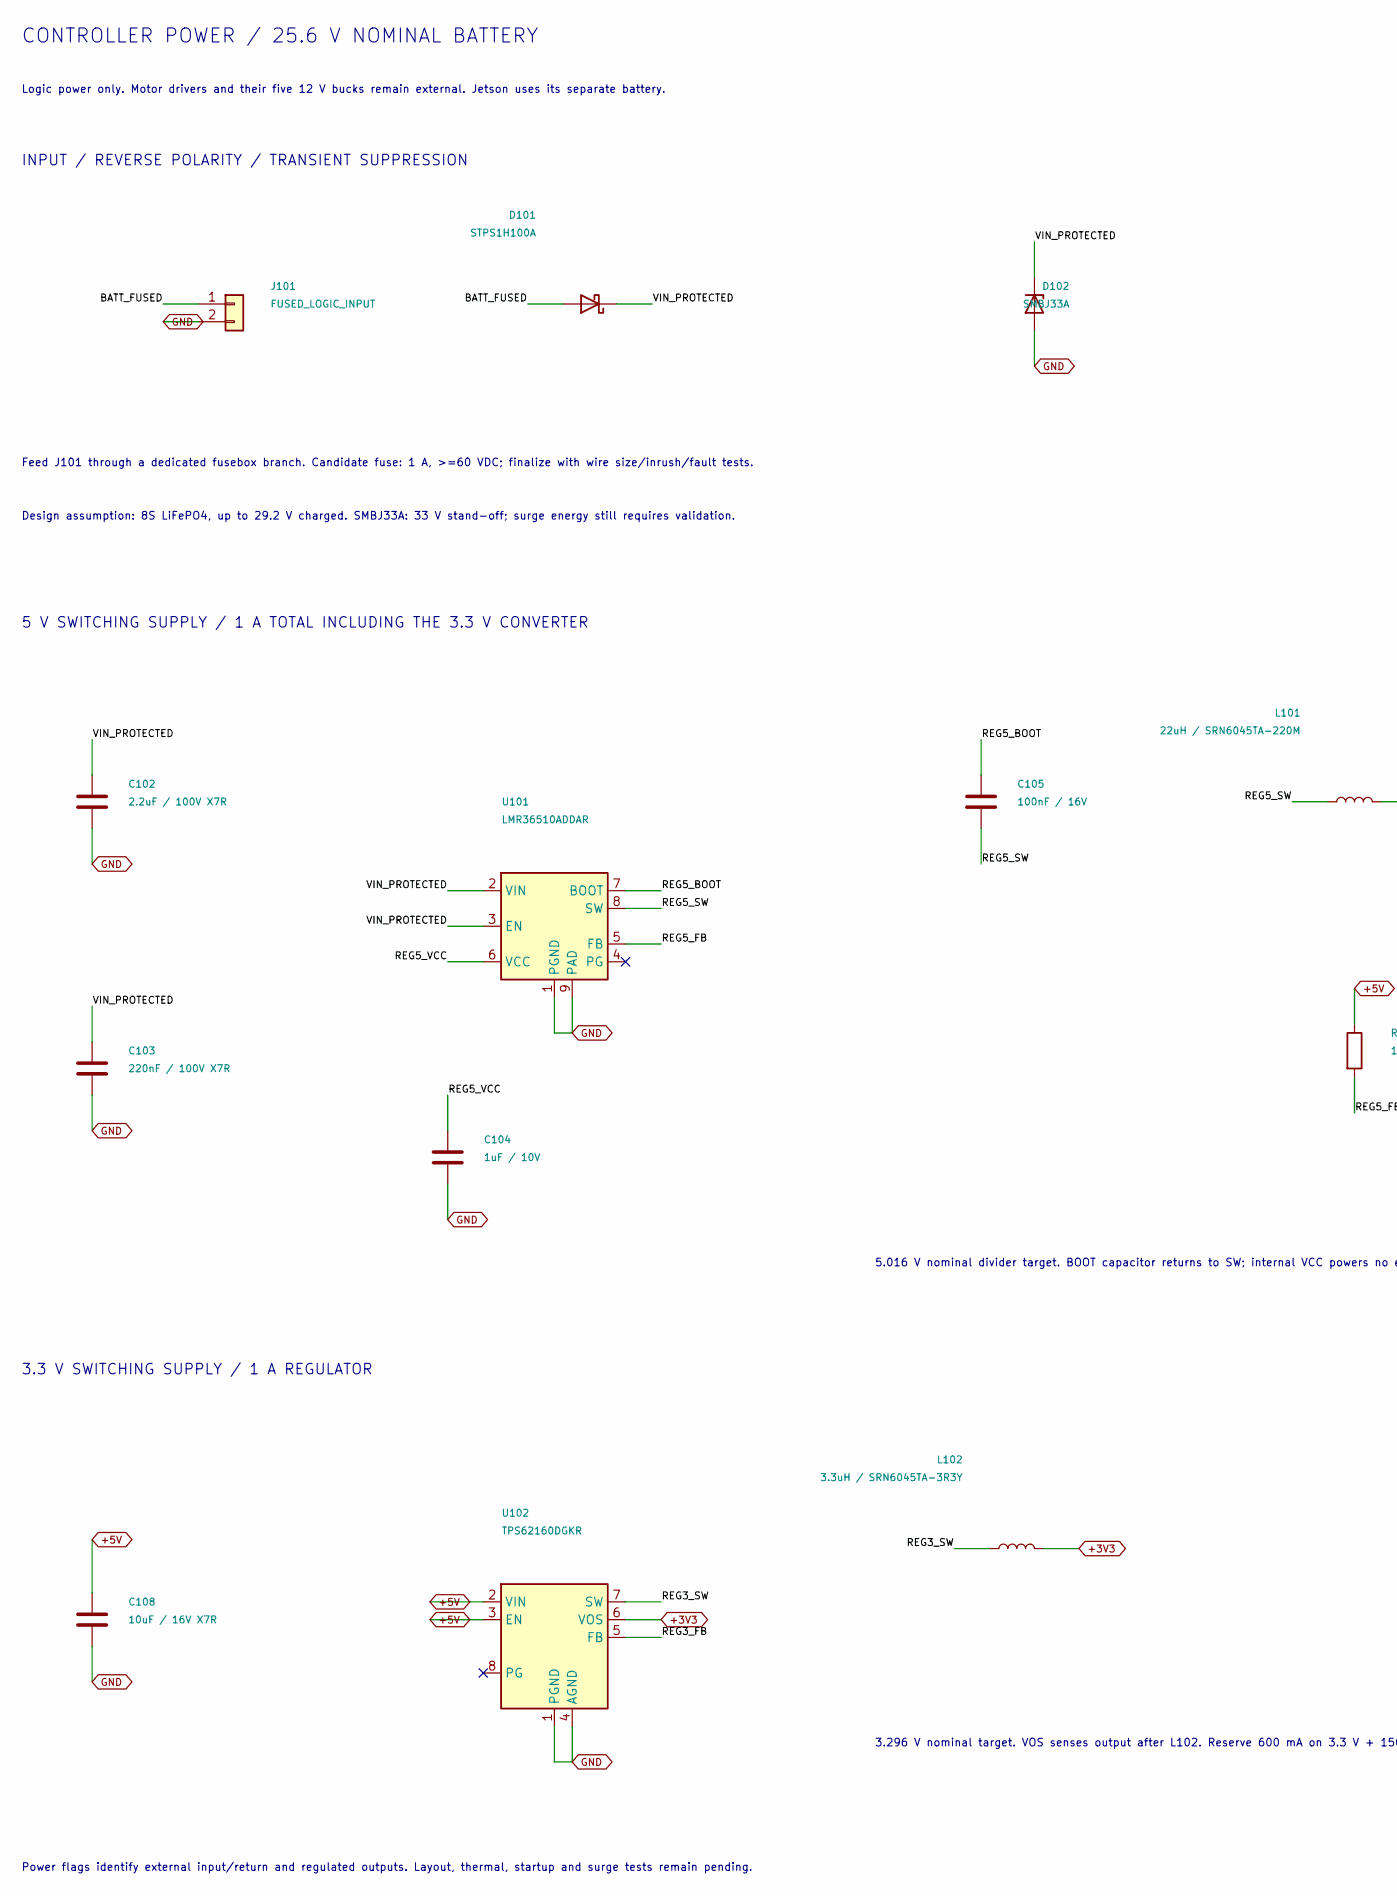
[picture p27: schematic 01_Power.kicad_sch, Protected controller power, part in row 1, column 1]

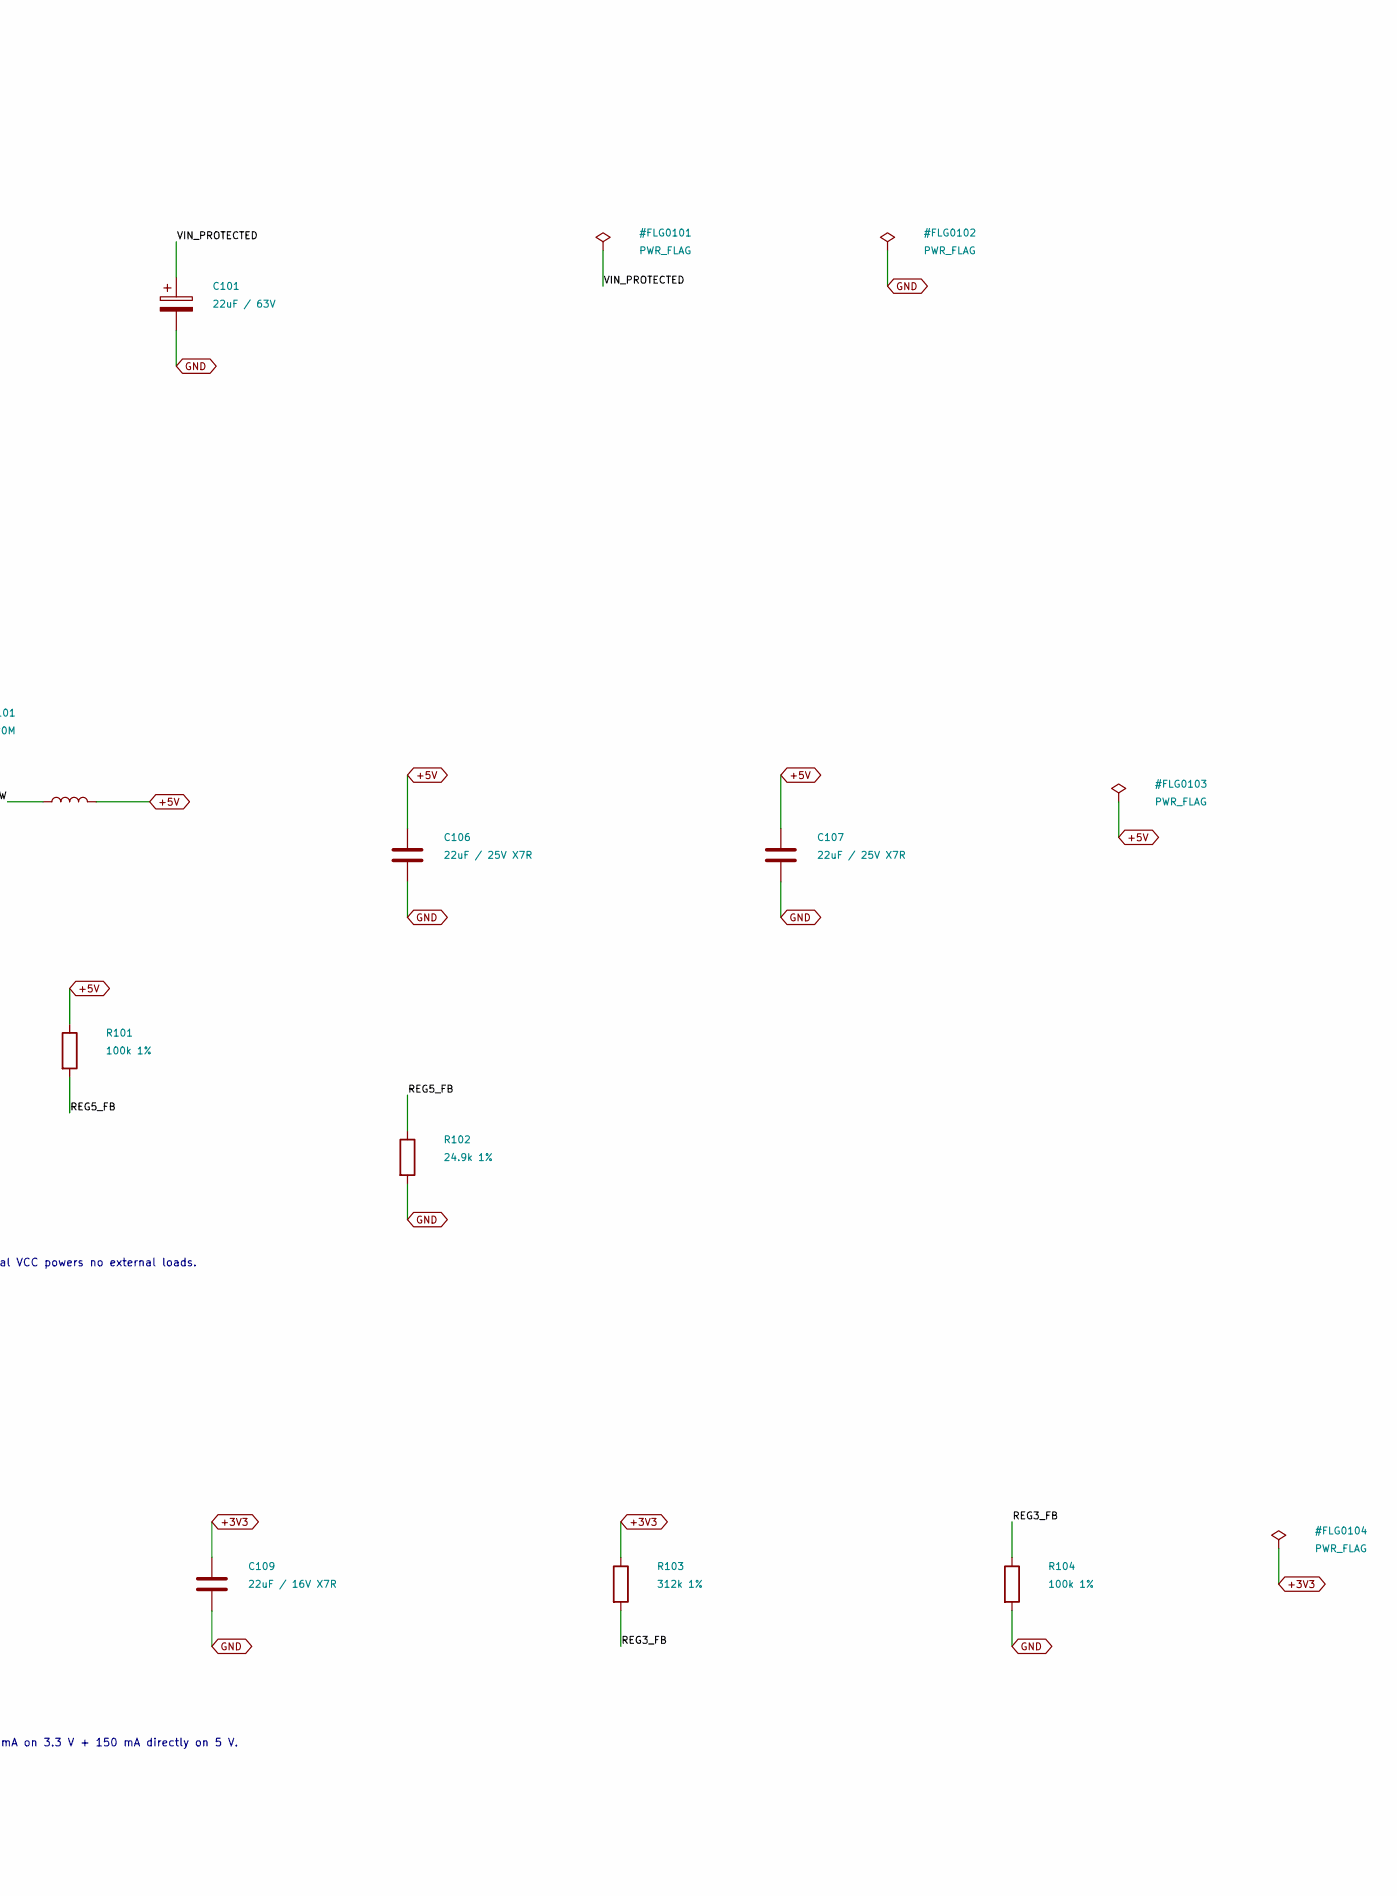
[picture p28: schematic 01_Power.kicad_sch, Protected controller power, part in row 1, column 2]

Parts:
C101: 22uF / 63V; CP_Radial_D8.0mm_P3.50mm
C102: 2.2uF / 100V X7R; C_1210_3225Metric
C103: 220nF / 100V X7R; C_0805_2012Metric
C104: 1uF / 10V; C_0805_2012Metric
C105: 100nF / 16V; C_0805_2012Metric
C106, C107: 22uF / 25V X7R; C_1210_3225Metric
C108: 10uF / 16V X7R; C_0805_2012Metric
C109: 22uF / 16V X7R; C_1206_3216Metric
D101: STPS1H100A; D_SMA
D102: SMBJ33A; D_SMB
J101: FUSED_LOGIC_INPUT; TerminalBlock_Phoenix_MKDS-1,5-2_1x02_P5.00mm_Horizontal
L101: 22uH / SRN6045TA-220M; L_Bourns_SRN6045TA
L102: 3.3uH / SRN6045TA-3R3Y; L_Bourns_SRN6045TA
R101, R104: 100k 1%; R_0603_1608Metric
R102: 24.9k 1%; R_0603_1608Metric
R103: 312k 1%; R_0603_1608Metric
U101: LMR36510ADDAR; Texas_HTSOP-8-1EP_3.9x4.9mm_P1.27mm_EP2.95x4.9mm_Mask2.4x3.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
U102: TPS62160DGKR; MSOP-8_3x3mm_P0.65mm

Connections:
+3V3: C109.1, L102.2, R103.1, U102.6 (VOS); also elsewhere on the board
+5V: C106.1, C107.1, C108.1, L101.2, R101.1, U102.2 (VIN), U102.3 (EN); also elsewhere on the board
/Power and protection/BATT_FUSED: D101.2 (A), J101.1
/Power and protection/REG3_FB: R103.2, R104.1, U102.5 (FB)
/Power and protection/REG3_SW: L102.1, U102.7 (SW)
/Power and protection/REG5_BOOT: C105.1, U101.7 (BOOT)
/Power and protection/REG5_FB: R101.2, R102.1, U101.5 (FB)
/Power and protection/REG5_SW: C105.2, L101.1, U101.8 (SW)
/Power and protection/REG5_VCC: C104.1, U101.6 (VCC)
/Power and protection/VIN_PROTECTED: C101.1, C102.1, C103.1, D101.1 (K), D102.1 (K), U101.2 (VIN), U101.3 (EN)
GND: C101.2, C102.2, C103.2, C104.2, C106.2, C107.2, C108.2, C109.2, D102.2 (A), J101.2, R102.2, R104.2, U101.1 (PGND), U101.9 (PAD), U102.1 (PGND), U102.4 (AGND); also elsewhere on the board

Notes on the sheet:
CONTROLLER POWER / 25.6 V NOMINAL BATTERY
Logic power only. Motor drivers and their five 12 V bucks remain external. Jetson uses its separate battery.
INPUT / REVERSE POLARITY / TRANSIENT SUPPRESSION
Feed J101 through a dedicated fusebox branch. Candidate fuse: 1 A, >=60 VDC; finalize with wire size/inrush/fault tests.
Design assumption: 8S LiFePO4, up to 29.2 V charged. SMBJ33A: 33 V stand-off; surge energy still requires validation.
5 V SWITCHING SUPPLY / 1 A TOTAL INCLUDING THE 3.3 V CONVERTER
5.016 V nominal divider target. BOOT capacitor returns to SW; internal VCC powers no external loads.
3.3 V SWITCHING SUPPLY / 1 A REGULATOR
3.296 V nominal target. VOS senses output after L102. Reserve 600 mA on 3.3 V + 150 mA directly on 5 V.
Power flags identify external input/return and regulated outputs. Layout, thermal, startup and surge tests remain pending.

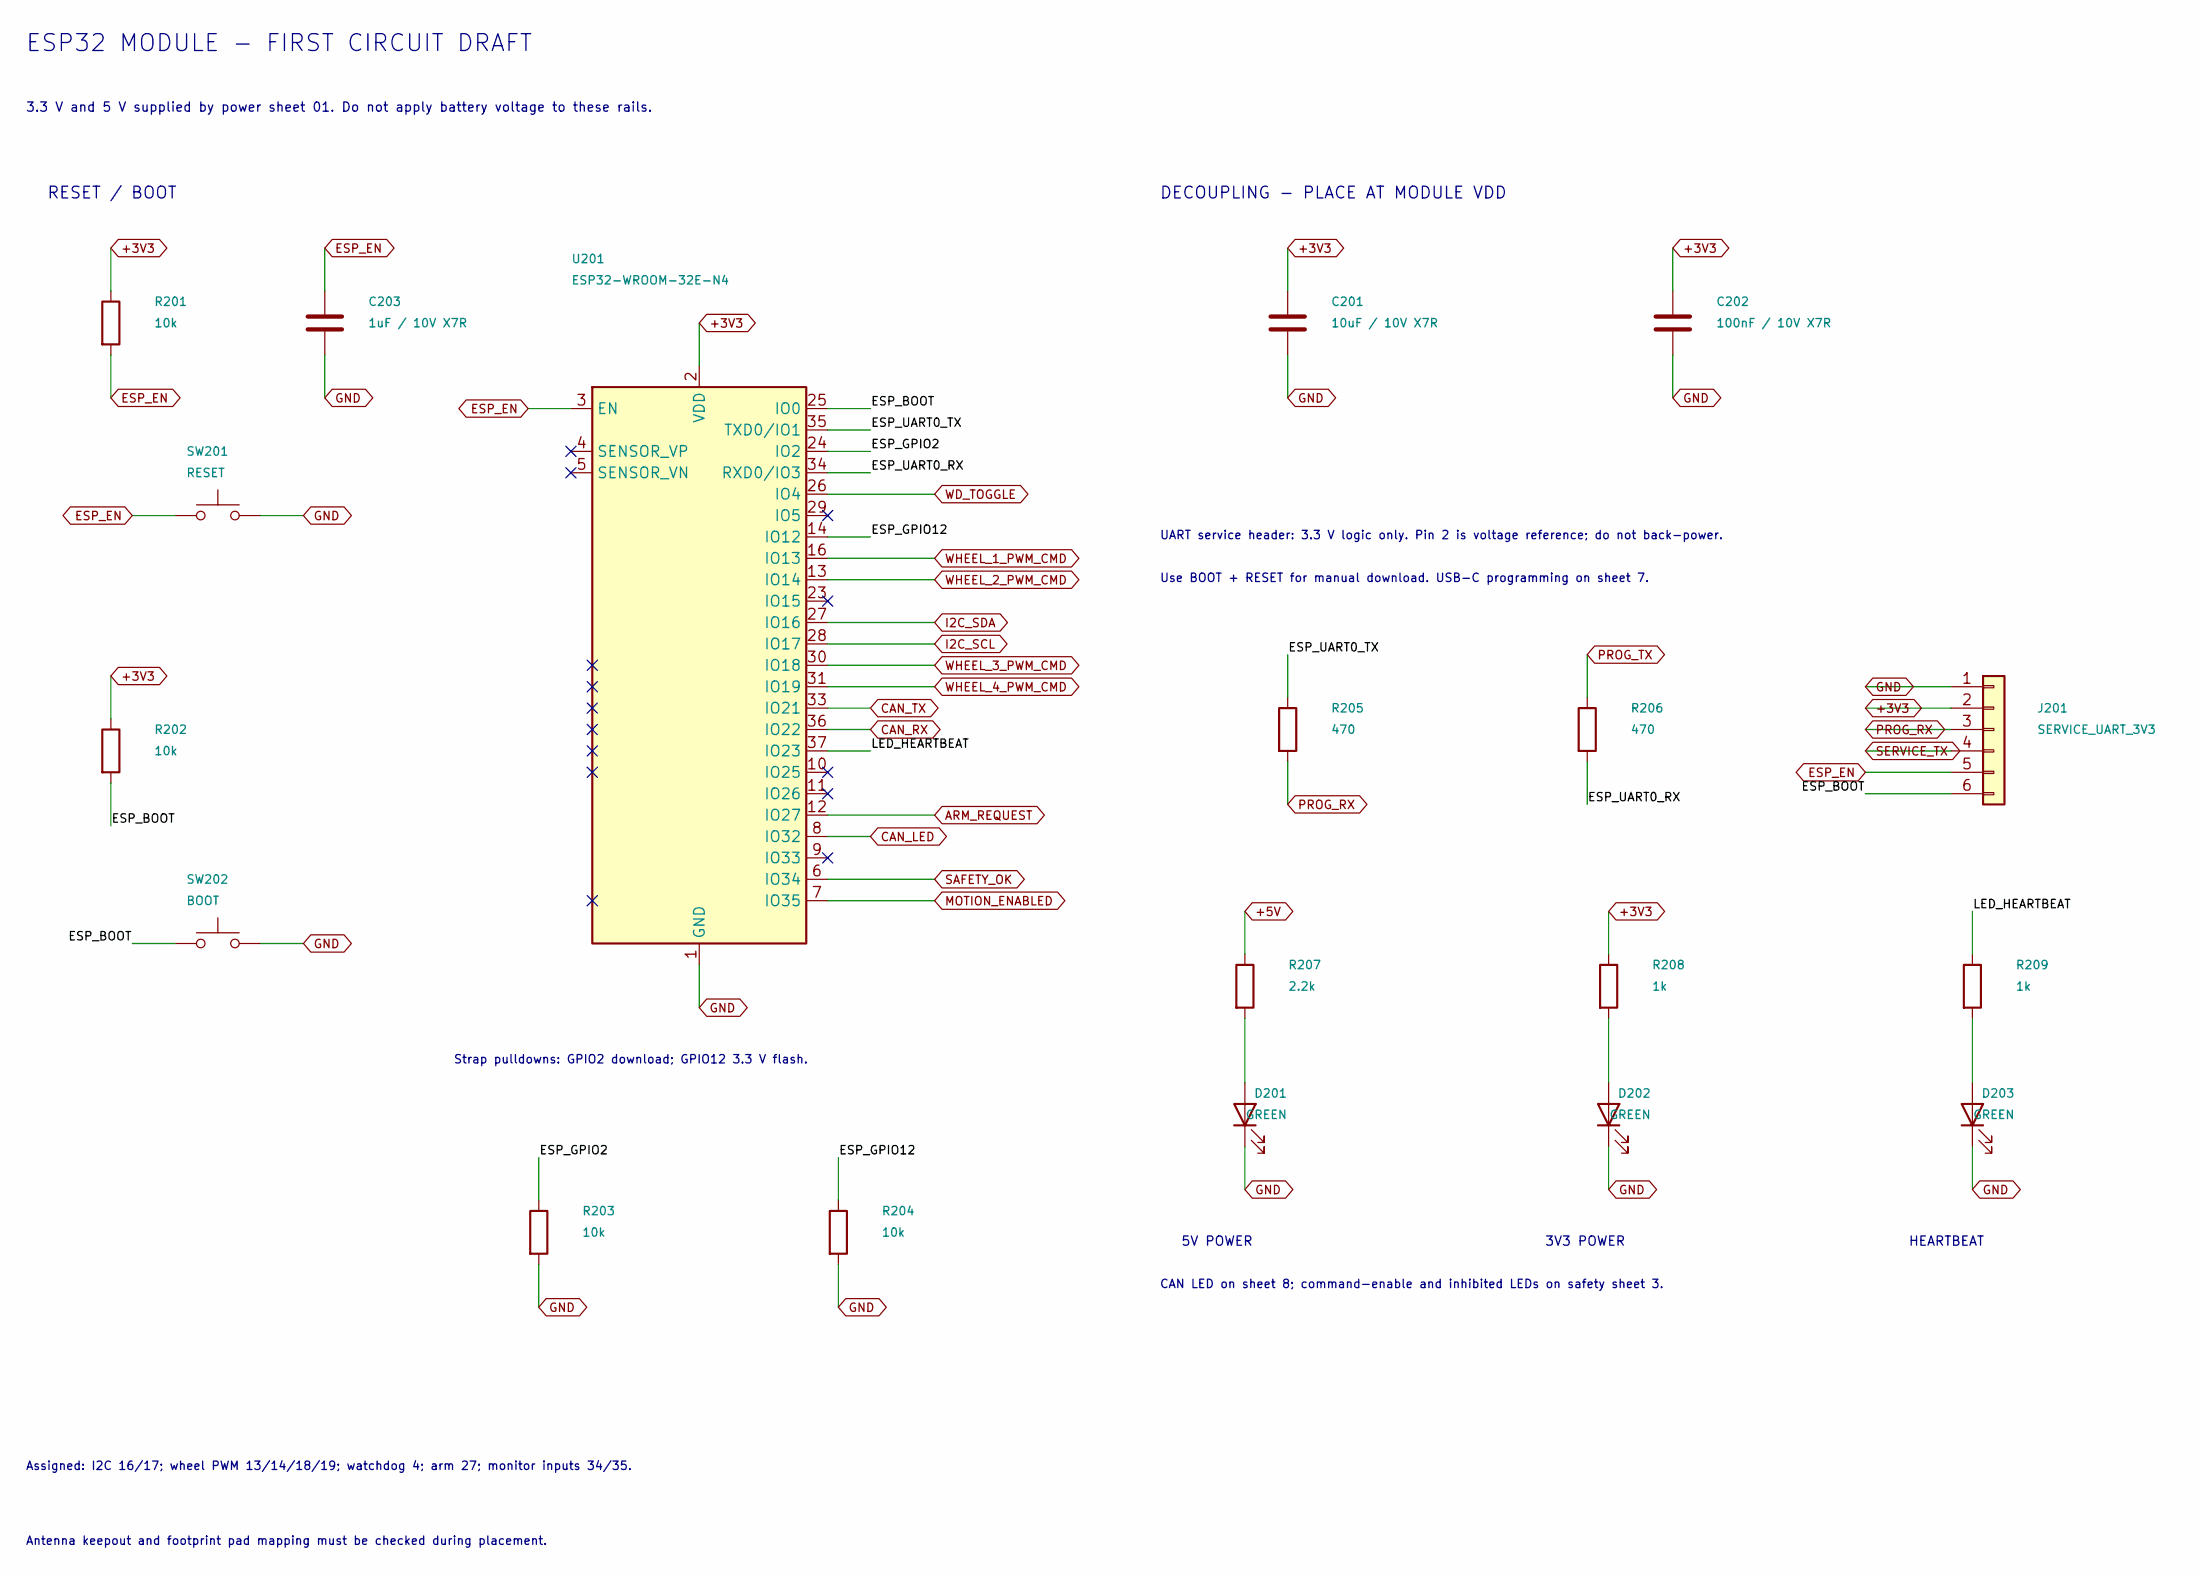
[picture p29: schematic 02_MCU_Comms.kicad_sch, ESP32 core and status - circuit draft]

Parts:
C201: 10uF / 10V X7R; C_0805_2012Metric
C202: 100nF / 10V X7R; C_0603_1608Metric
C203: 1uF / 10V X7R; C_0603_1608Metric
D201, D202, D203: GREEN; LED_0603_1608Metric
J201: SERVICE_UART_3V3; PinHeader_1x06_P2.54mm_Vertical
R201, R202, R203, R204: 10k; R_0603_1608Metric
R205, R206: 470; R_0603_1608Metric
R207: 2.2k; R_0603_1608Metric
R208, R209: 1k; R_0603_1608Metric
SW201: RESET; SW_SPST_TL3342
SW202: BOOT; SW_SPST_TL3342
U201: ESP32-WROOM-32E-N4; ESP32-WROOM-32D

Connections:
+3V3: C201.1, C202.1, J201.2, R201.1, R202.1, R208.1, U201.2 (VDD); also elsewhere on the board
+5V: R207.1; also elsewhere on the board
/MCU and communications/ESP_BOOT: J201.6, R202.2, SW202.1, U201.25 (IO0)
/MCU and communications/ESP_GPIO2: R203.1, U201.24 (IO2)
/MCU and communications/ESP_GPIO12: R204.1, U201.14 (IO12)
/MCU and communications/ESP_UART0_RX: R206.2, U201.34 (RXD0/IO3)
/MCU and communications/ESP_UART0_TX: R205.1, U201.35 (TXD0/IO1)
/MCU and communications/LED_HEARTBEAT: R209.1, U201.37 (IO23)
ARM_REQUEST: U201.12 (IO27); also elsewhere on the board
CAN_LED: U201.8 (IO32); also elsewhere on the board
CAN_RX: U201.36 (IO22); also elsewhere on the board
CAN_TX: U201.33 (IO21); also elsewhere on the board
ESP_EN: C203.1, J201.5, R201.2, SW201.1, U201.3 (EN); also elsewhere on the board
GND: C201.2, C202.2, C203.2, D201.1 (K), D202.1 (K), D203.1 (K), J201.1, R203.2, R204.2, SW201.2, SW202.2, U201.1 (GND), U201.15 (GND), U201.38 (GND), U201.39 (GND); also elsewhere on the board
I2C_SCL: U201.28 (IO17); also elsewhere on the board
I2C_SDA: U201.27 (IO16); also elsewhere on the board
MOTION_ENABLED: U201.7 (IO35); also elsewhere on the board
unnamed: D201.2 (A), R207.2
unnamed: D202.2 (A), R208.2
unnamed: D203.2 (A), R209.2
PROG_RX: J201.3, R205.2; also elsewhere on the board
PROG_TX: R206.1; also elsewhere on the board
SAFETY_OK: U201.6 (IO34); also elsewhere on the board
SERVICE_TX: J201.4; also elsewhere on the board
WD_TOGGLE: U201.26 (IO4); also elsewhere on the board
WHEEL_1_PWM_CMD: U201.16 (IO13); also elsewhere on the board
WHEEL_2_PWM_CMD: U201.13 (IO14); also elsewhere on the board
WHEEL_3_PWM_CMD: U201.30 (IO18); also elsewhere on the board
WHEEL_4_PWM_CMD: U201.31 (IO19); also elsewhere on the board

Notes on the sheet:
5V POWER
3V3 POWER
HEARTBEAT
ESP32 MODULE - FIRST CIRCUIT DRAFT
3.3 V and 5 V supplied by power sheet 01. Do not apply battery voltage to these rails.
RESET / BOOT
DECOUPLING - PLACE AT MODULE VDD
UART service header: 3.3 V logic only. Pin 2 is voltage reference; do not back-power.
Use BOOT + RESET for manual download. USB-C programming on sheet 7.
Strap pulldowns: GPIO2 download; GPIO12 3.3 V flash.
Assigned: I2C 16/17; wheel PWM 13/14/18/19; watchdog 4; arm 27; monitor inputs 34/35.
CAN LED on sheet 8; command-enable and inhibited LEDs on safety sheet 3.
Antenna keepout and footprint pad mapping must be checked during placement.

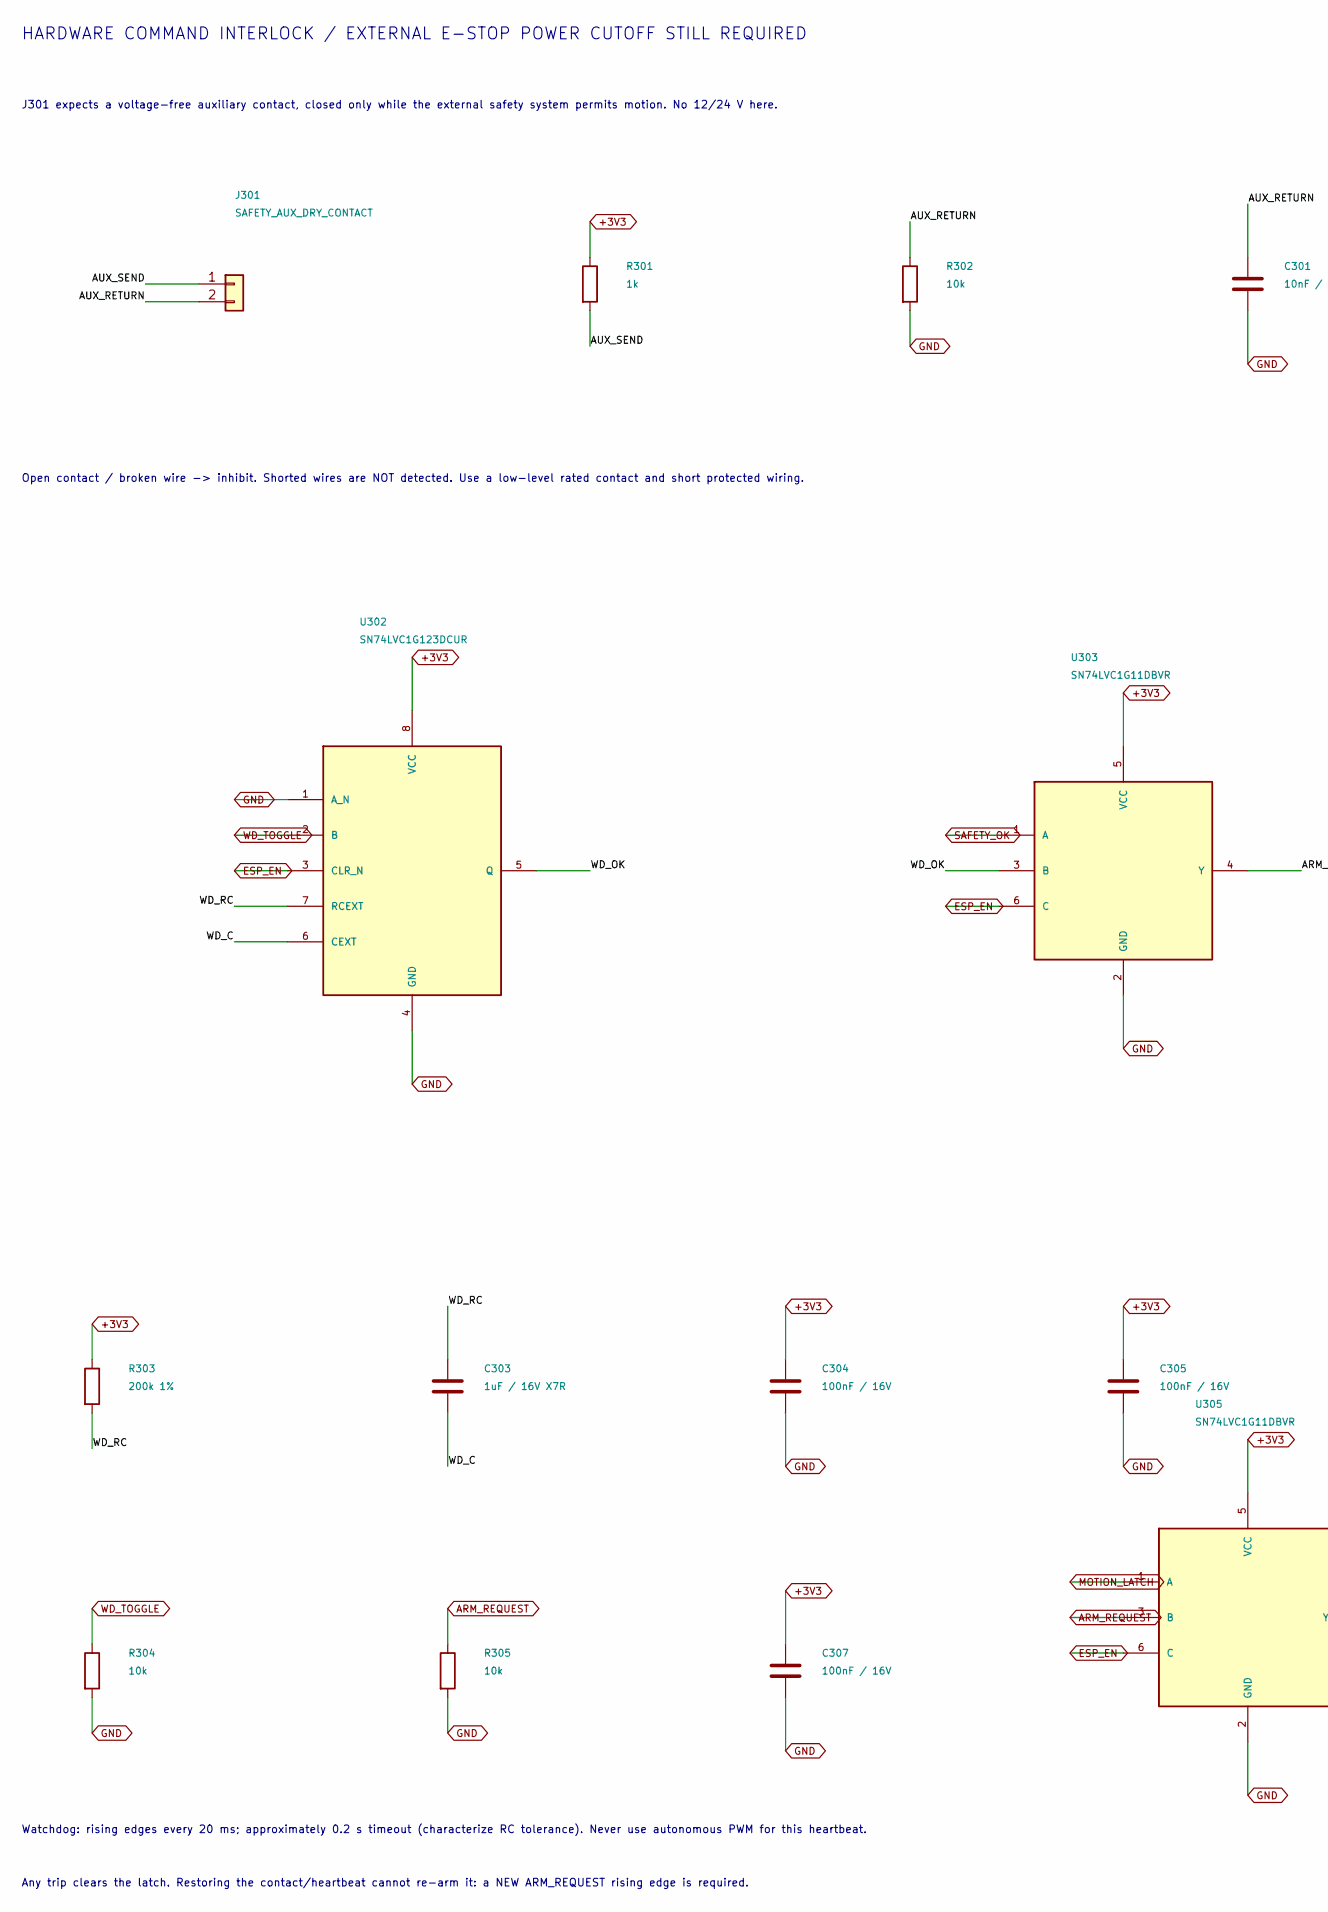
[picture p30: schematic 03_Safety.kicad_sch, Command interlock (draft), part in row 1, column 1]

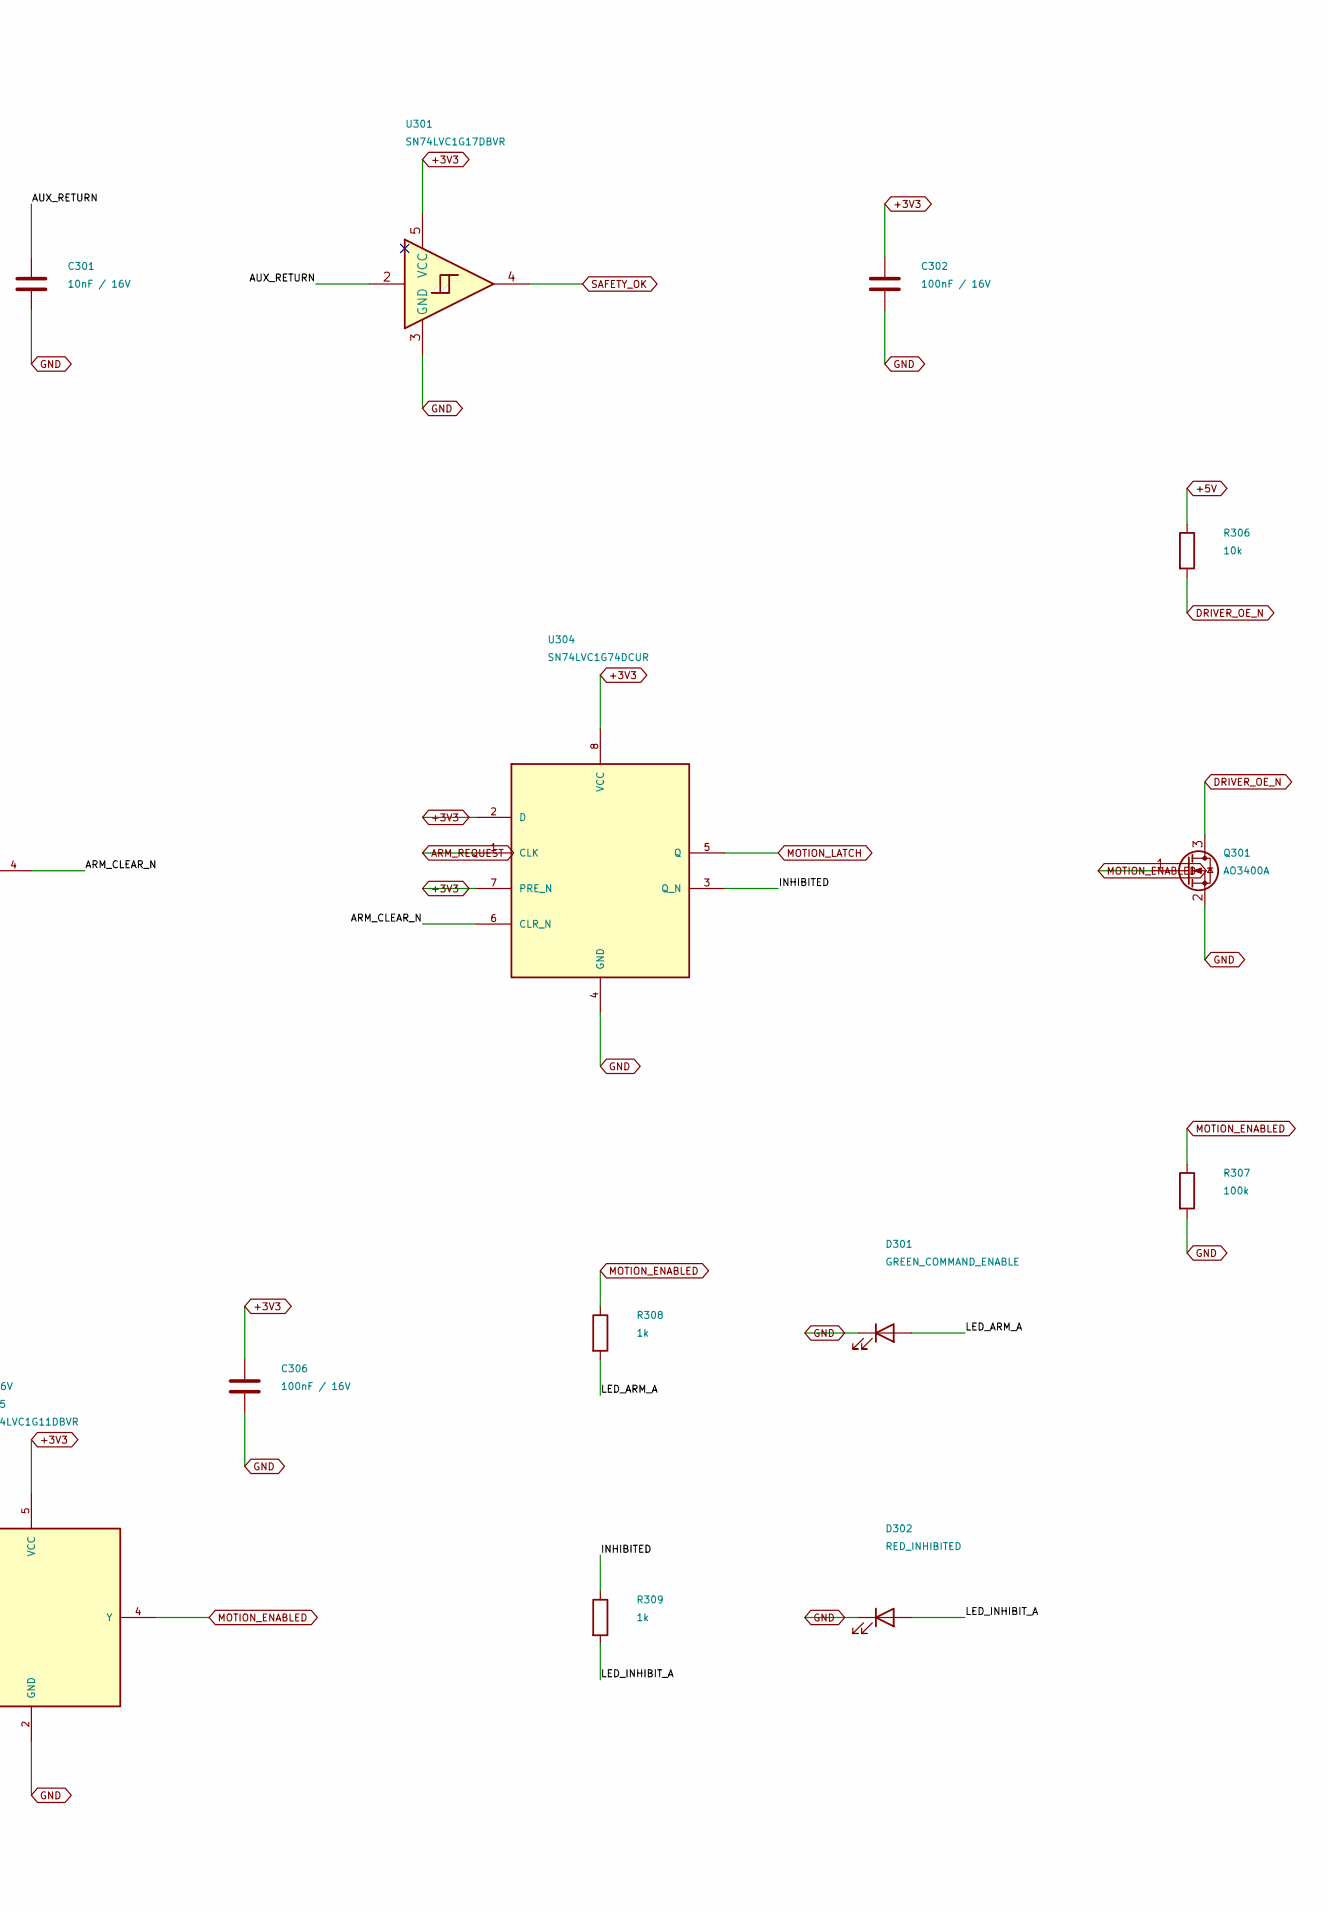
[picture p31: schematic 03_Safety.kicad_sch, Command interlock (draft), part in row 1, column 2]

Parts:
C301: 10nF / 16V; C_0603_1608Metric
C302, C304, C305, C306, C307: 100nF / 16V; C_0603_1608Metric
C303: 1uF / 16V X7R; C_0603_1608Metric
D301: GREEN_COMMAND_ENABLE; LED_0603_1608Metric
D302: RED_INHIBITED; LED_0603_1608Metric
J301: SAFETY_AUX_DRY_CONTACT; TerminalBlock_Phoenix_MKDS-1,5-2_1x02_P5.00mm_Horizontal
Q301: AO3400A; SOT-23
R301, R308, R309: 1k; R_0603_1608Metric
R302, R304, R305, R306: 10k; R_0603_1608Metric
R303: 200k 1%; R_0603_1608Metric
R307: 100k; R_0603_1608Metric
U301: SN74LVC1G17DBVR; SOT-23-5
U302: SN74LVC1G123DCUR; VSSOP-8_2.3x2mm_P0.5mm
U303, U305: SN74LVC1G11DBVR; SOT-23-6
U304: SN74LVC1G74DCUR; VSSOP-8_2.3x2mm_P0.5mm

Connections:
+3V3: C302.1, C304.1, C305.1, C306.1, C307.1, R301.1, R303.1, U301.5 (VCC), U302.8 (VCC), U303.5 (VCC), U304.2 (D), U304.7 (PRE_N), U304.8 (VCC), U305.5 (VCC); also elsewhere on the board
+5V: R306.1; also elsewhere on the board
/Hardware E-stop/ARM_CLEAR_N: U303.4 (Y), U304.6 (CLR_N)
/Hardware E-stop/AUX_RETURN: C301.1, J301.2, R302.1, U301.2
/Hardware E-stop/AUX_SEND: J301.1, R301.2
/Hardware E-stop/INHIBITED: R309.1, U304.3 (Q_N)
/Hardware E-stop/LED_ARM_A: D301.2 (A), R308.2
/Hardware E-stop/LED_INHIBIT_A: D302.2 (A), R309.2
/Hardware E-stop/WD_C: C303.2, U302.6 (CEXT)
/Hardware E-stop/WD_OK: U302.5 (Q), U303.3 (B)
/Hardware E-stop/WD_RC: C303.1, R303.2, U302.7 (RCEXT)
ARM_REQUEST: R305.1, U304.1 (CLK), U305.3 (B); also elsewhere on the board
DRIVER_OE_N: Q301.3 (D), R306.2; also elsewhere on the board
ESP_EN: U302.3 (CLR_N), U303.6 (C), U305.6 (C); also elsewhere on the board
GND: C301.2, C302.2, C304.2, C305.2, C306.2, C307.2, D301.1 (K), D302.1 (K), Q301.2 (S), R302.2, R304.2, R305.2, R307.2, U301.3 (GND), U302.1 (A_N), U302.4 (GND), U303.2 (GND), U304.4 (GND), U305.2 (GND); also elsewhere on the board
MOTION_ENABLED: Q301.1 (G), R307.1, R308.1, U305.4 (Y); also elsewhere on the board
MOTION_LATCH: U304.5 (Q), U305.1 (A)
SAFETY_OK: U301.4, U303.1 (A); also elsewhere on the board
WD_TOGGLE: R304.1, U302.2 (B); also elsewhere on the board

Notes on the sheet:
HARDWARE COMMAND INTERLOCK / EXTERNAL E-STOP POWER CUTOFF STILL REQUIRED
J301 expects a voltage-free auxiliary contact, closed only while the external safety system permits motion. No 12/24 V here.
Open contact / broken wire -> inhibit. Shorted wires are NOT detected. Use a low-level rated contact and short protected wiring.
Watchdog: rising edges every 20 ms; approximately 0.2 s timeout (characterize RC tolerance). Never use autonomous PWM for this heartbeat.
Any trip clears the latch. Restoring the contact/heartbeat cannot re-arm it: a NEW ARM_REQUEST rising edge is required.

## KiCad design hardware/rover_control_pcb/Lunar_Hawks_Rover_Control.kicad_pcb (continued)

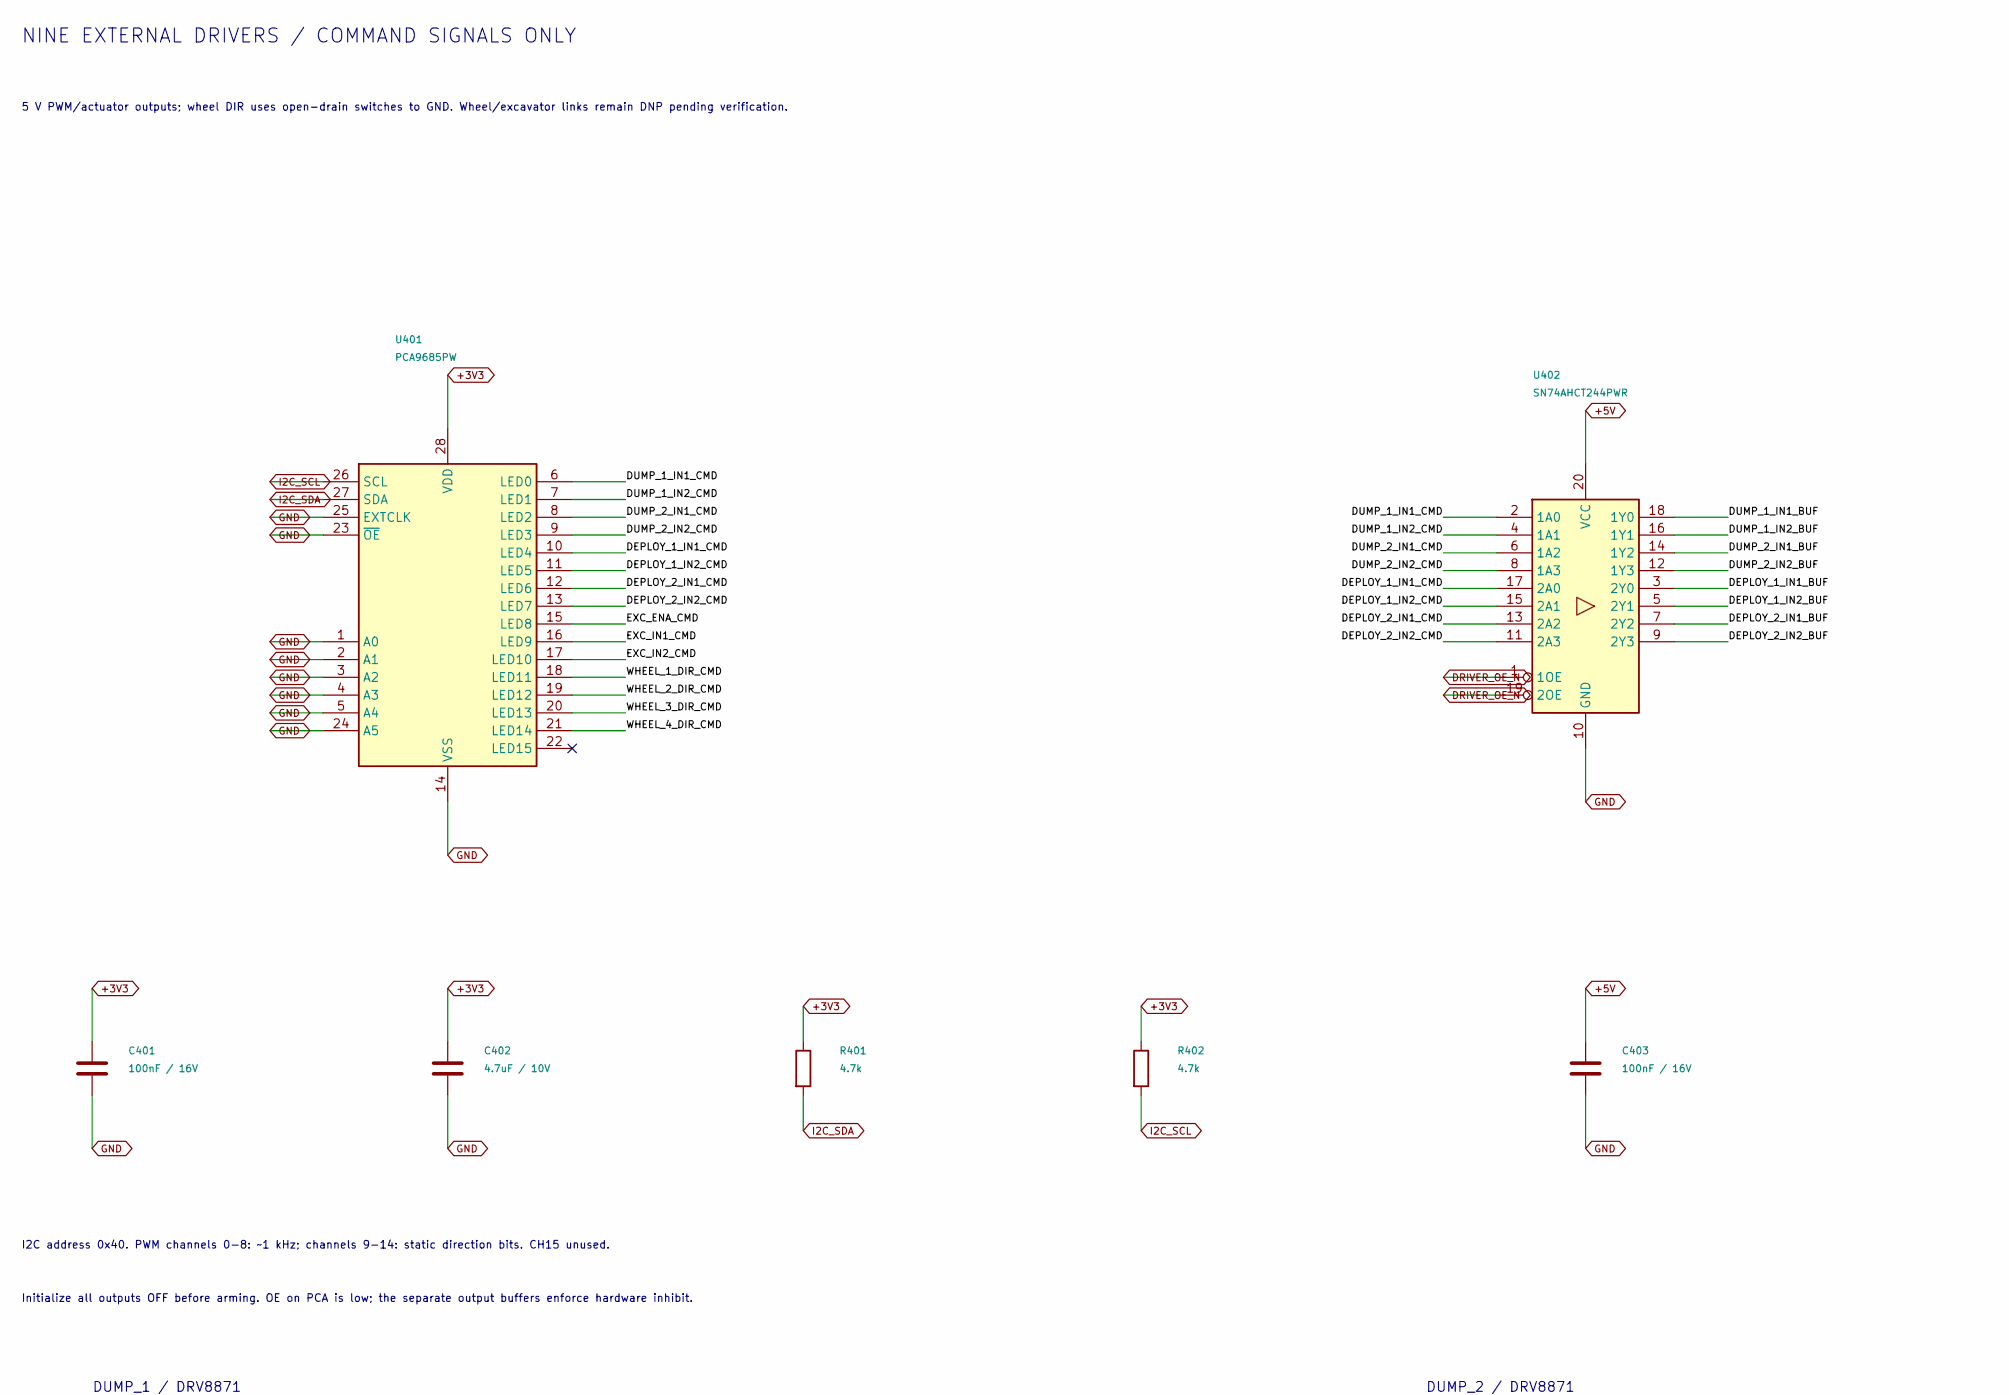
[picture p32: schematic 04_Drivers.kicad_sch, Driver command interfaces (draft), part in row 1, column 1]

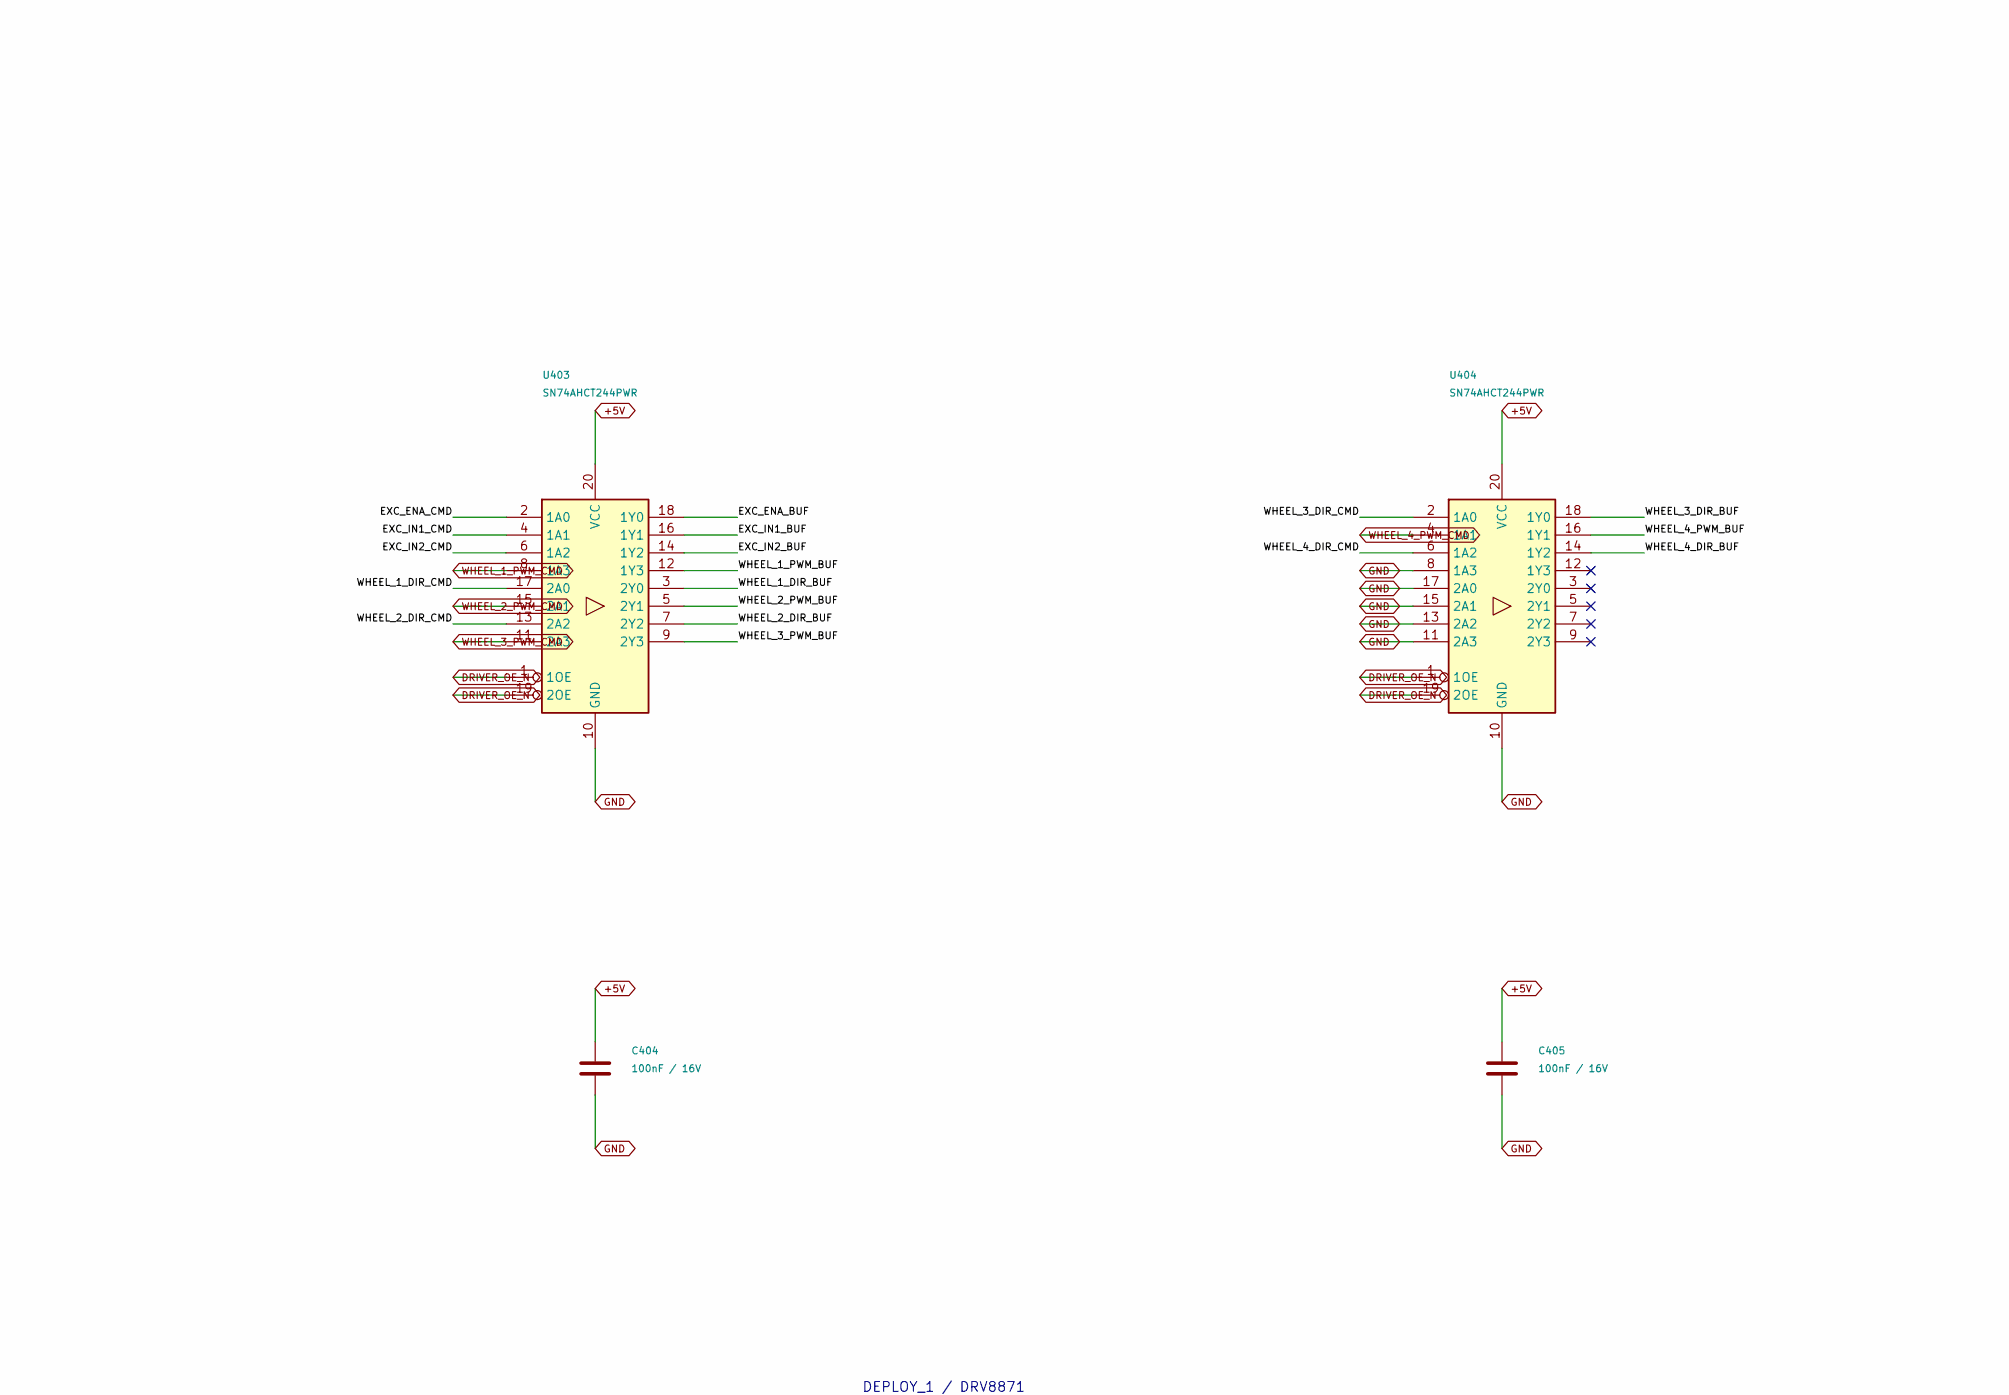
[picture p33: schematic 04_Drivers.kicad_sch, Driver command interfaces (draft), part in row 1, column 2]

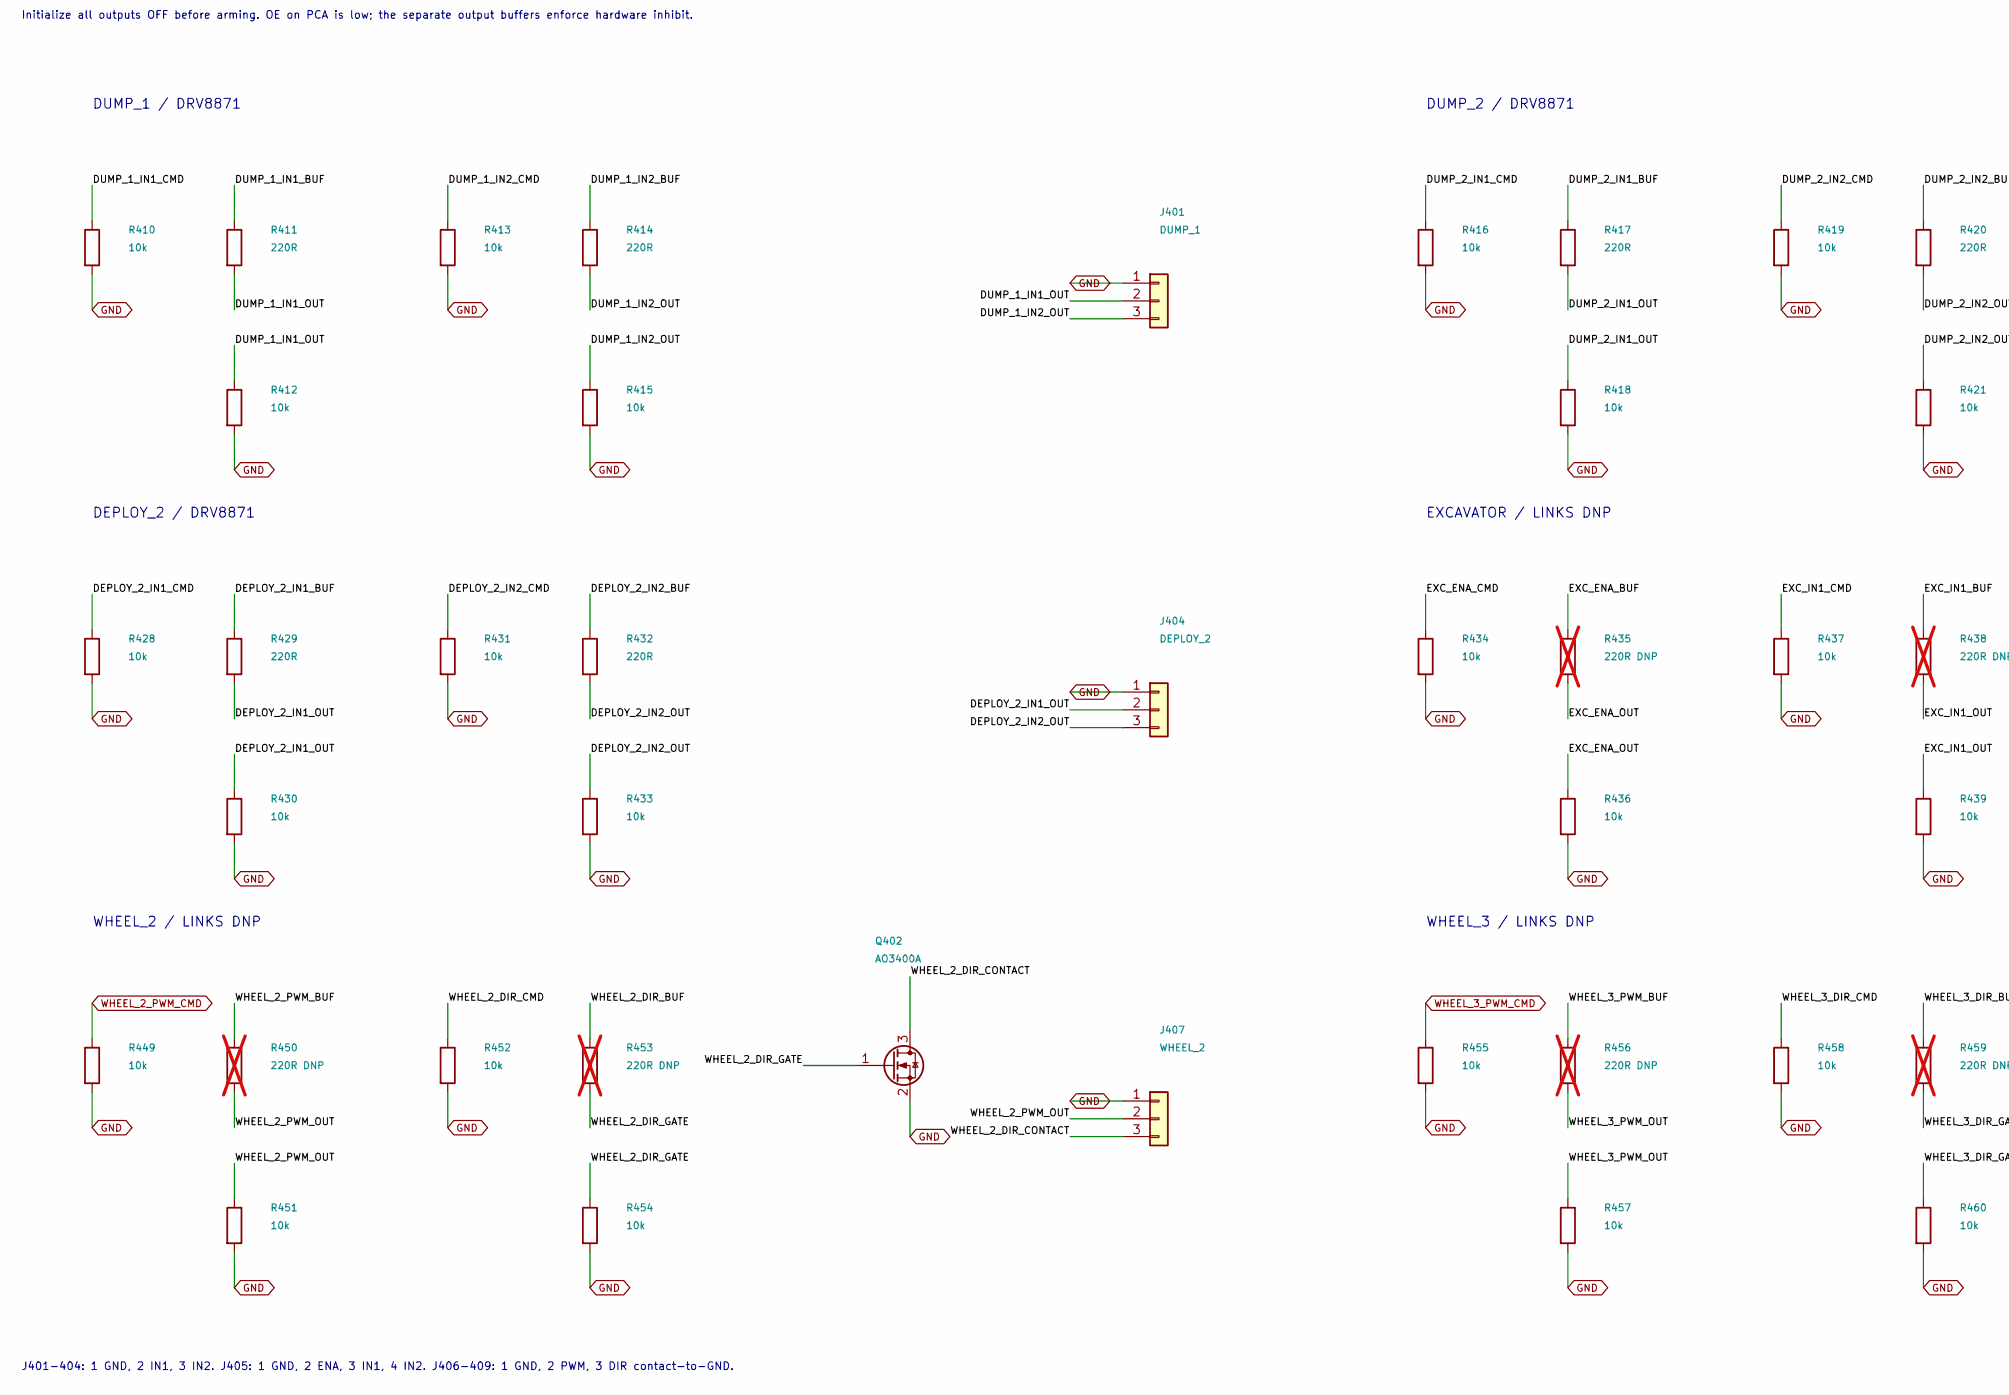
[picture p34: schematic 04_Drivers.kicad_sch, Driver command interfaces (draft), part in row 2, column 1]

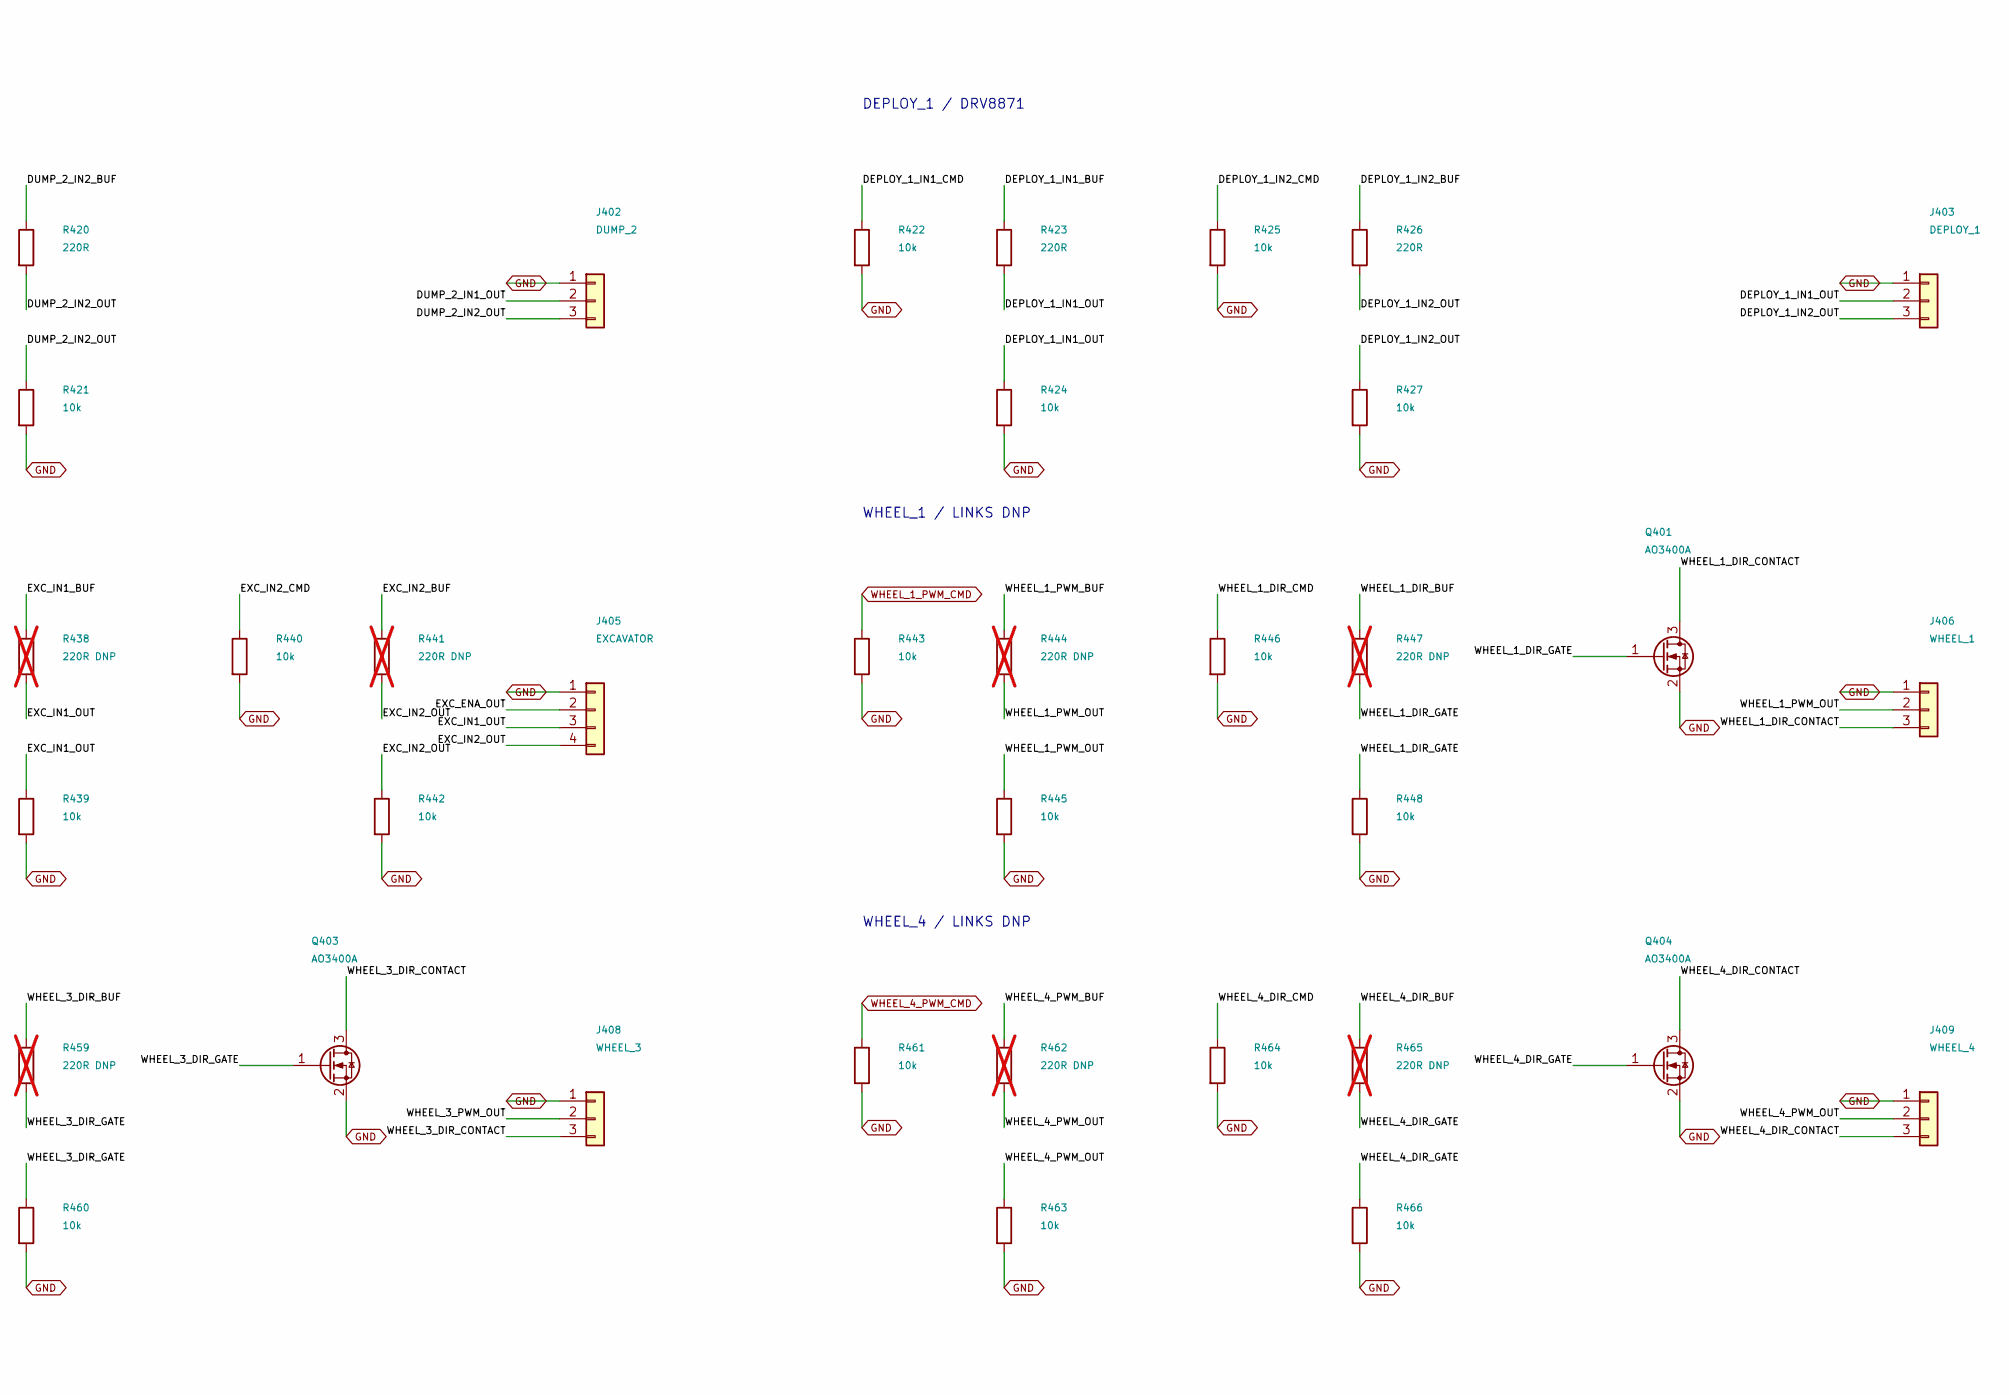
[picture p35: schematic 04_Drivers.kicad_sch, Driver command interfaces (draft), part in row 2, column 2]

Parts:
C401, C403, C404, C405: 100nF / 16V; C_0603_1608Metric
C402: 4.7uF / 10V; C_0603_1608Metric
J401: DUMP_1; PinHeader_1x03_P2.54mm_Vertical
J402: DUMP_2; PinHeader_1x03_P2.54mm_Vertical
J403: DEPLOY_1; PinHeader_1x03_P2.54mm_Vertical
J404: DEPLOY_2; PinHeader_1x03_P2.54mm_Vertical
J405: EXCAVATOR; PinHeader_1x04_P2.54mm_Vertical
J406: WHEEL_1; PinHeader_1x03_P2.54mm_Vertical
J407: WHEEL_2; PinHeader_1x03_P2.54mm_Vertical
J408: WHEEL_3; PinHeader_1x03_P2.54mm_Vertical
J409: WHEEL_4; PinHeader_1x03_P2.54mm_Vertical
Q401, Q402, Q403, Q404: AO3400A; SOT-23
R401, R402: 4.7k; R_0603_1608Metric
R410, R412, R413, R415, R416, R418, R419, R421, R422, R424, R425, R427, R428, R430, R431, R433, R434, R436, R437, R439, R440, R442, R443, R445, R446, R448, R449, R451, R452, R454, R455, R457, R458, R460, R461, R463, R464, R466: 10k; R_0603_1608Metric
R411, R414, R417, R420, R423, R426, R429, R432: 220R; R_0603_1608Metric
R435, R438, R441, R444, R447, R450, R453, R456, R459, R462, R465: 220R DNP; R_0603_1608Metric; not fitted
U401: PCA9685PW; TSSOP-28_4.4x9.7mm_P0.65mm
U402, U403, U404: SN74AHCT244PWR; TSSOP-20_4.4x6.5mm_P0.65mm

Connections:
+3V3: C401.1, C402.1, R401.1, R402.1, U401.28 (VDD); also elsewhere on the board
+5V: C403.1, C404.1, C405.1, U402.20 (VCC), U403.20 (VCC), U404.20 (VCC); also elsewhere on the board
/External driver interfaces/DEPLOY_1_IN1_BUF: R423.1, U402.3 (2Y0)
/External driver interfaces/DEPLOY_1_IN1_CMD: R422.1, U401.10 (LED4), U402.17 (2A0)
/External driver interfaces/DEPLOY_1_IN1_OUT: J403.2, R423.2, R424.1
/External driver interfaces/DEPLOY_1_IN2_BUF: R426.1, U402.5 (2Y1)
/External driver interfaces/DEPLOY_1_IN2_CMD: R425.1, U401.11 (LED5), U402.15 (2A1)
/External driver interfaces/DEPLOY_1_IN2_OUT: J403.3, R426.2, R427.1
/External driver interfaces/DEPLOY_2_IN1_BUF: R429.1, U402.7 (2Y2)
/External driver interfaces/DEPLOY_2_IN1_CMD: R428.1, U401.12 (LED6), U402.13 (2A2)
/External driver interfaces/DEPLOY_2_IN1_OUT: J404.2, R429.2, R430.1
/External driver interfaces/DEPLOY_2_IN2_BUF: R432.1, U402.9 (2Y3)
/External driver interfaces/DEPLOY_2_IN2_CMD: R431.1, U401.13 (LED7), U402.11 (2A3)
/External driver interfaces/DEPLOY_2_IN2_OUT: J404.3, R432.2, R433.1
/External driver interfaces/DUMP_1_IN1_BUF: R411.1, U402.18 (1Y0)
/External driver interfaces/DUMP_1_IN1_CMD: R410.1, U401.6 (LED0), U402.2 (1A0)
/External driver interfaces/DUMP_1_IN1_OUT: J401.2, R411.2, R412.1
/External driver interfaces/DUMP_1_IN2_BUF: R414.1, U402.16 (1Y1)
/External driver interfaces/DUMP_1_IN2_CMD: R413.1, U401.7 (LED1), U402.4 (1A1)
/External driver interfaces/DUMP_1_IN2_OUT: J401.3, R414.2, R415.1
/External driver interfaces/DUMP_2_IN1_BUF: R417.1, U402.14 (1Y2)
/External driver interfaces/DUMP_2_IN1_CMD: R416.1, U401.8 (LED2), U402.6 (1A2)
/External driver interfaces/DUMP_2_IN1_OUT: J402.2, R417.2, R418.1
/External driver interfaces/DUMP_2_IN2_BUF: R420.1, U402.12 (1Y3)
/External driver interfaces/DUMP_2_IN2_CMD: R419.1, U401.9 (LED3), U402.8 (1A3)
/External driver interfaces/DUMP_2_IN2_OUT: J402.3, R420.2, R421.1
/External driver interfaces/EXC_ENA_BUF: R435.1, U403.18 (1Y0)
/External driver interfaces/EXC_ENA_CMD: R434.1, U401.15 (LED8), U403.2 (1A0)
/External driver interfaces/EXC_ENA_OUT: J405.2, R435.2, R436.1
/External driver interfaces/EXC_IN1_BUF: R438.1, U403.16 (1Y1)
/External driver interfaces/EXC_IN1_CMD: R437.1, U401.16 (LED9), U403.4 (1A1)
/External driver interfaces/EXC_IN1_OUT: J405.3, R438.2, R439.1
/External driver interfaces/EXC_IN2_BUF: R441.1, U403.14 (1Y2)
/External driver interfaces/EXC_IN2_CMD: R440.1, U401.17 (LED10), U403.6 (1A2)
/External driver interfaces/EXC_IN2_OUT: J405.4, R441.2, R442.1
/External driver interfaces/WHEEL_1_DIR_BUF: R447.1, U403.3 (2Y0)
/External driver interfaces/WHEEL_1_DIR_CMD: R446.1, U401.18 (LED11), U403.17 (2A0)
/External driver interfaces/WHEEL_1_DIR_CONTACT: J406.3, Q401.3 (D)
/External driver interfaces/WHEEL_1_DIR_GATE: Q401.1 (G), R447.2, R448.1
/External driver interfaces/WHEEL_1_PWM_BUF: R444.1, U403.12 (1Y3)
/External driver interfaces/WHEEL_1_PWM_OUT: J406.2, R444.2, R445.1
/External driver interfaces/WHEEL_2_DIR_BUF: R453.1, U403.7 (2Y2)
/External driver interfaces/WHEEL_2_DIR_CMD: R452.1, U401.19 (LED12), U403.13 (2A2)
/External driver interfaces/WHEEL_2_DIR_CONTACT: J407.3, Q402.3 (D)
/External driver interfaces/WHEEL_2_DIR_GATE: Q402.1 (G), R453.2, R454.1
/External driver interfaces/WHEEL_2_PWM_BUF: R450.1, U403.5 (2Y1)
/External driver interfaces/WHEEL_2_PWM_OUT: J407.2, R450.2, R451.1
/External driver interfaces/WHEEL_3_DIR_BUF: R459.1, U404.18 (1Y0)
/External driver interfaces/WHEEL_3_DIR_CMD: R458.1, U401.20 (LED13), U404.2 (1A0)
/External driver interfaces/WHEEL_3_DIR_CONTACT: J408.3, Q403.3 (D)
/External driver interfaces/WHEEL_3_DIR_GATE: Q403.1 (G), R459.2, R460.1
/External driver interfaces/WHEEL_3_PWM_BUF: R456.1, U403.9 (2Y3)
/External driver interfaces/WHEEL_3_PWM_OUT: J408.2, R456.2, R457.1
/External driver interfaces/WHEEL_4_DIR_BUF: R465.1, U404.14 (1Y2)
/External driver interfaces/WHEEL_4_DIR_CMD: R464.1, U401.21 (LED14), U404.6 (1A2)
/External driver interfaces/WHEEL_4_DIR_CONTACT: J409.3, Q404.3 (D)
/External driver interfaces/WHEEL_4_DIR_GATE: Q404.1 (G), R465.2, R466.1
/External driver interfaces/WHEEL_4_PWM_BUF: R462.1, U404.16 (1Y1)
/External driver interfaces/WHEEL_4_PWM_OUT: J409.2, R462.2, R463.1
DRIVER_OE_N: U402.1 (1OE), U402.19 (2OE), U403.1 (1OE), U403.19 (2OE), U404.1 (1OE), U404.19 (2OE); also elsewhere on the board
GND: C401.2, C402.2, C403.2, C404.2, C405.2, J401.1, J402.1, J403.1, J404.1, J405.1, J406.1, J407.1, J408.1, J409.1, Q401.2 (S), Q402.2 (S), Q403.2 (S), Q404.2 (S), R410.2, R412.2, R413.2, R415.2, R416.2, R418.2, R419.2, R421.2, R422.2, R424.2, R425.2, R427.2, R428.2, R430.2, R431.2, R433.2, R434.2, R436.2, R437.2, R439.2, R440.2, R442.2, R443.2, R445.2, R446.2, R448.2, R449.2, R451.2, R452.2, R454.2, R455.2, R457.2, R458.2, R460.2, R461.2, R463.2, R464.2, R466.2, U401.1 (A0), U401.2 (A1), U401.3 (A2), U401.4 (A3), U401.5 (A4), U401.14 (VSS), U401.23 (~OE), U401.24 (A5), U401.25 (EXTCLK), U402.10 (GND), U403.10 (GND), U404.8 (1A3), U404.10 (GND), U404.11 (2A3), U404.13 (2A2), U404.15 (2A1), U404.17 (2A0); also elsewhere on the board
I2C_SCL: R402.2, U401.26 (SCL); also elsewhere on the board
I2C_SDA: R401.2, U401.27 (SDA); also elsewhere on the board
WHEEL_1_PWM_CMD: R443.1, U403.8 (1A3); also elsewhere on the board
WHEEL_2_PWM_CMD: R449.1, U403.15 (2A1); also elsewhere on the board
WHEEL_3_PWM_CMD: R455.1, U403.11 (2A3); also elsewhere on the board
WHEEL_4_PWM_CMD: R461.1, U404.4 (1A1); also elsewhere on the board

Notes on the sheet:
NINE EXTERNAL DRIVERS / COMMAND SIGNALS ONLY
5 V PWM/actuator outputs; wheel DIR uses open-drain switches to GND. Wheel/excavator links remain DNP pending verification.
I2C address 0x40. PWM channels 0-8: ~1 kHz; channels 9-14: static direction bits. CH15 unused.
Initialize all outputs OFF before arming. OE on PCA is low; the separate output buffers enforce hardware inhibit.
DUMP_1 / DRV8871
DUMP_2 / DRV8871
DEPLOY_1 / DRV8871
DEPLOY_2 / DRV8871
EXCAVATOR / LINKS DNP
WHEEL_1 / LINKS DNP
WHEEL_2 / LINKS DNP
WHEEL_3 / LINKS DNP
WHEEL_4 / LINKS DNP
J401-404: 1 GND, 2 IN1, 3 IN2. J405: 1 GND, 2 ENA, 3 IN1, 4 IN2. J406-409: 1 GND, 2 PWM, 3 DIR contact-to-GND.

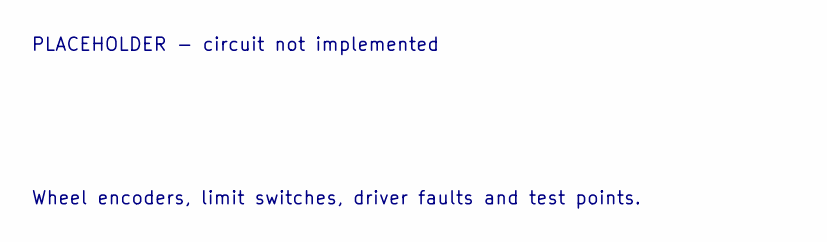
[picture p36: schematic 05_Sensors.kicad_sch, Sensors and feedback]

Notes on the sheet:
PLACEHOLDER - circuit not implemented
Wheel encoders, limit switches, driver faults and test points.

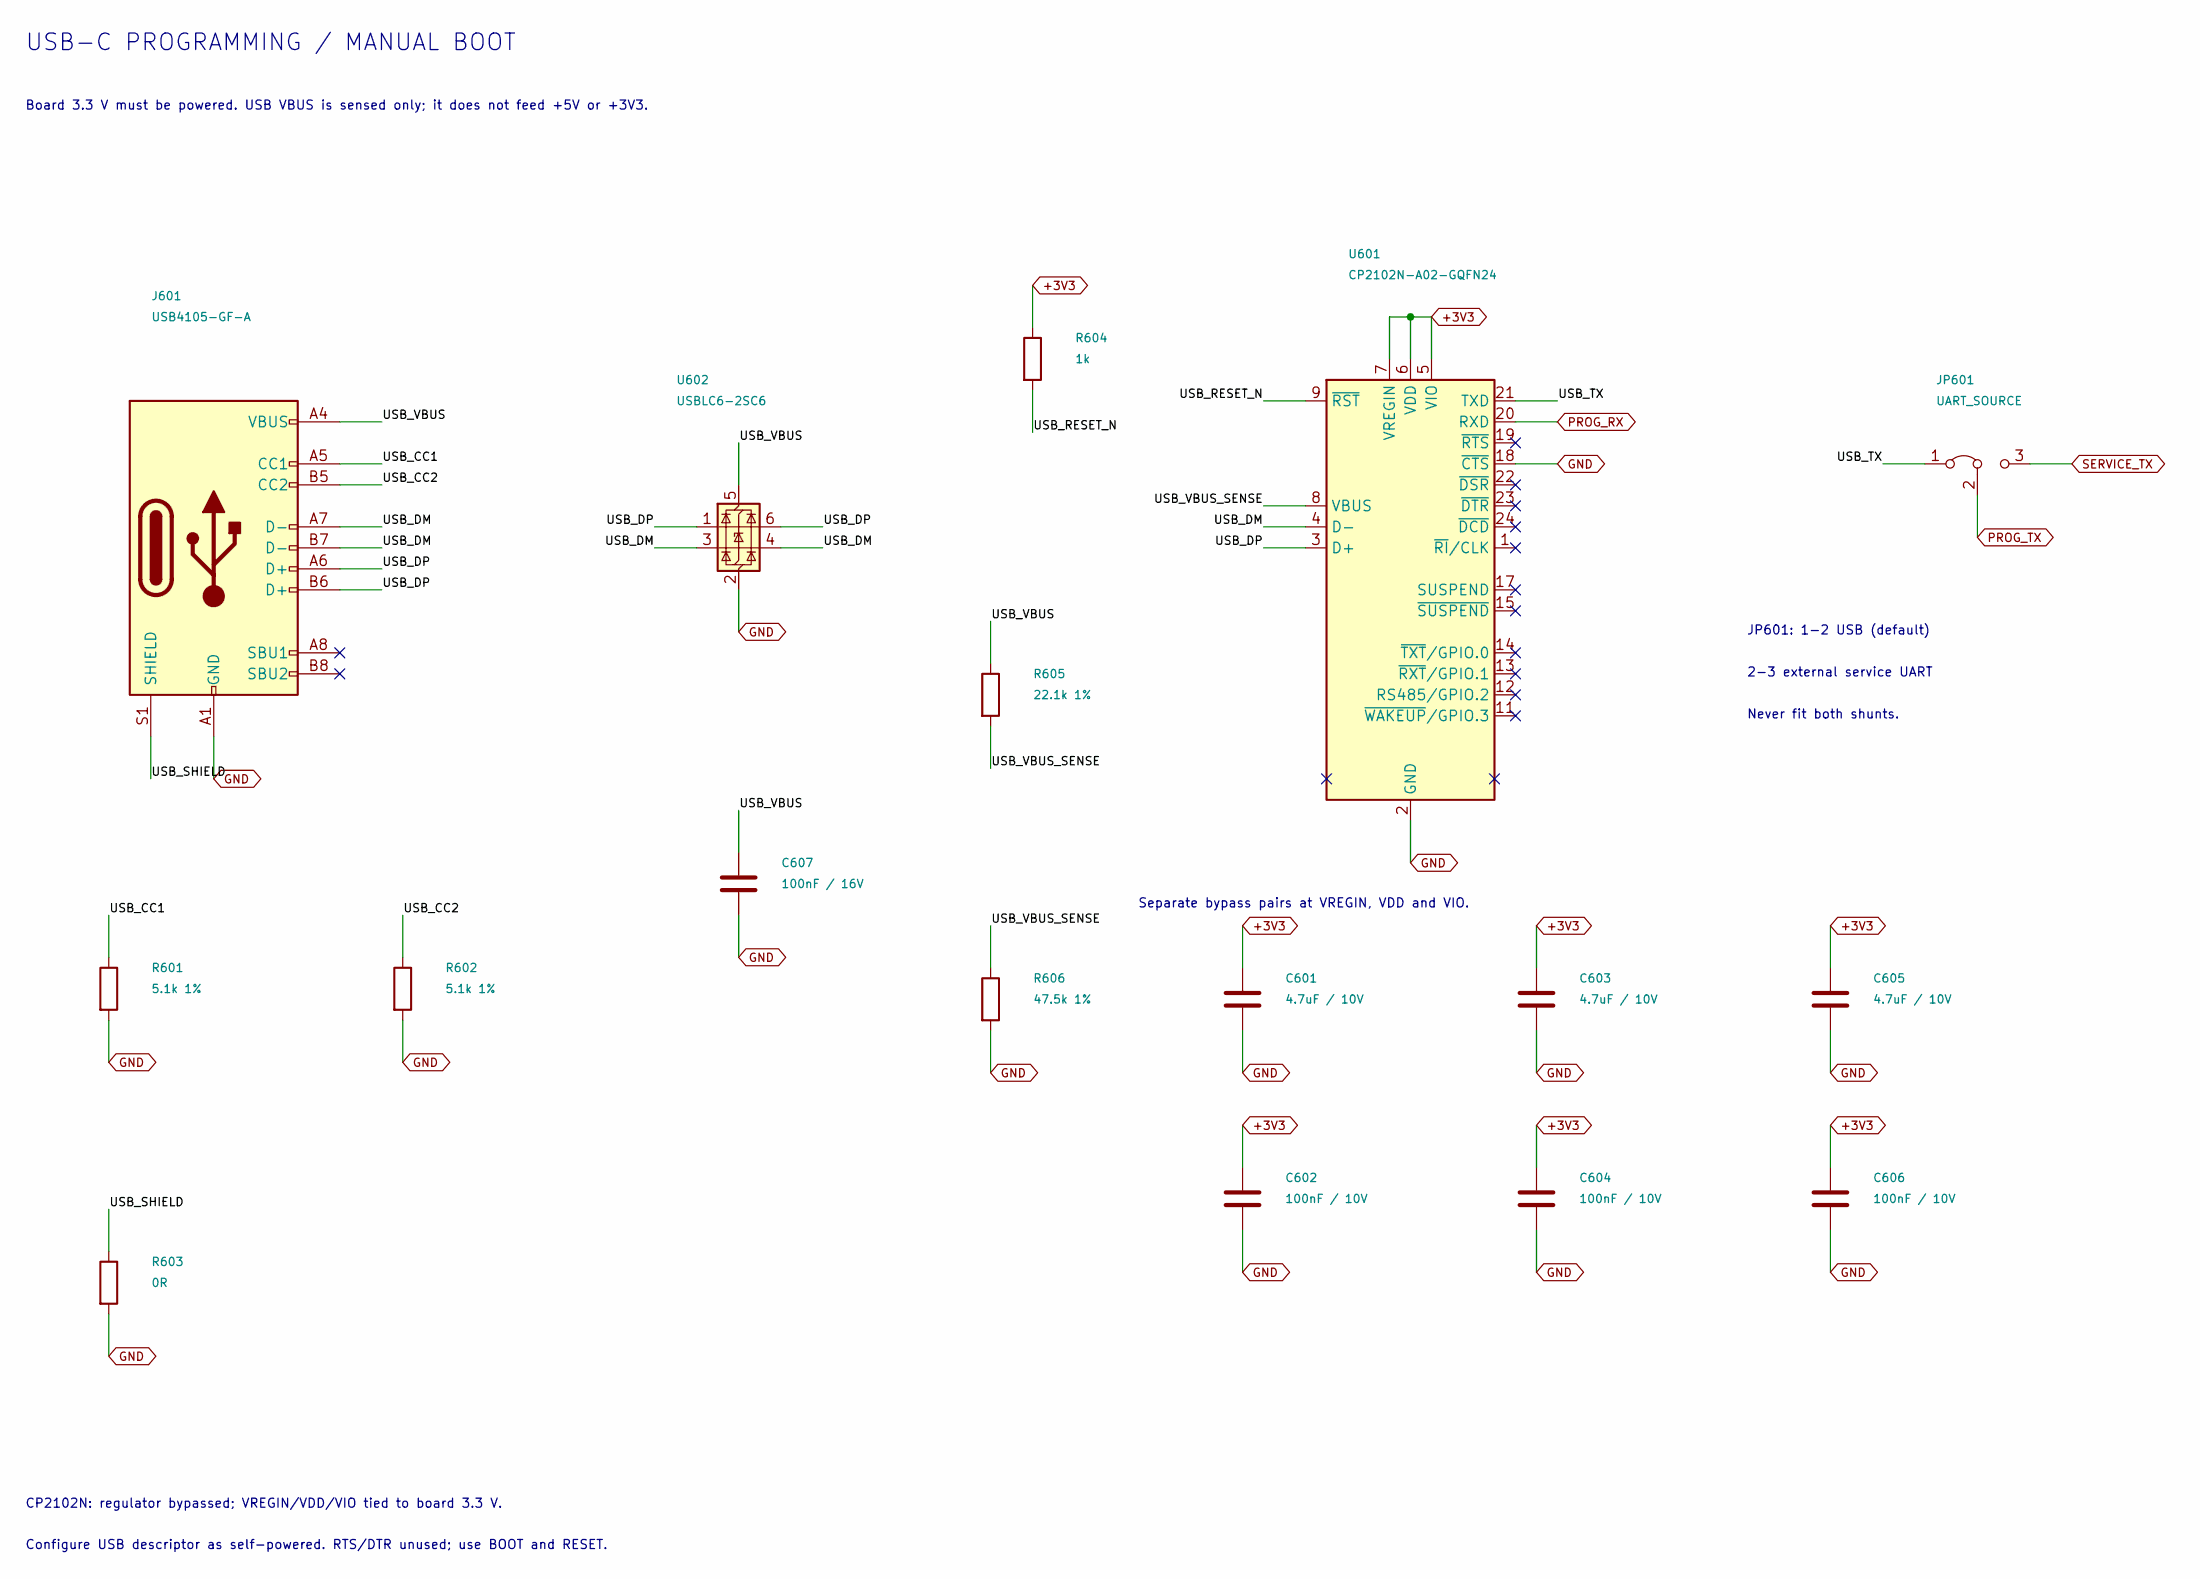
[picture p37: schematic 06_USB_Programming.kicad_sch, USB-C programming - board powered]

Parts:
C601, C603, C605: 4.7uF / 10V; C_0805_2012Metric
C602, C604, C606: 100nF / 10V; C_0603_1608Metric
C607: 100nF / 16V; C_0603_1608Metric
J601: USB4105-GF-A; USB_C_Receptacle_GCT_USB4105-xx-A_16P_TopMnt_Horizontal
JP601: UART_SOURCE; PinHeader_1x03_P2.54mm_Vertical
R601, R602: 5.1k 1%; R_0603_1608Metric
R603: 0R; R_0603_1608Metric
R604: 1k; R_0603_1608Metric
R605: 22.1k 1%; R_0603_1608Metric
R606: 47.5k 1%; R_0603_1608Metric
U601: CP2102N-A02-GQFN24; QFN-24-1EP_4x4mm_P0.5mm_EP2.6x2.6mm
U602: USBLC6-2SC6; SOT-23-6

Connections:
+3V3: C601.1, C602.1, C603.1, C604.1, C605.1, C606.1, R604.1, U601.5 (VIO), U601.6 (VDD), U601.7 (VREGIN); also elsewhere on the board
/USB-C programming - board powered/USB_CC1: J601.A5 (CC1), R601.1
/USB-C programming - board powered/USB_CC2: J601.B5 (CC2), R602.1
/USB-C programming - board powered/USB_DM: J601.A7 (D-), J601.B7 (D-), U601.4 (D-), U602.3 (I/O2), U602.4 (I/O2)
/USB-C programming - board powered/USB_DP: J601.A6 (D+), J601.B6 (D+), U601.3 (D+), U602.1 (I/O1), U602.6 (I/O1)
/USB-C programming - board powered/USB_RESET_N: R604.2, U601.9 (~RST)
/USB-C programming - board powered/USB_SHIELD: J601.S1 (SHIELD), R603.1
/USB-C programming - board powered/USB_TX: JP601.1 (A), U601.21 (TXD)
/USB-C programming - board powered/USB_VBUS: C607.1, J601.A4 (VBUS), J601.A9 (VBUS), J601.B4 (VBUS), J601.B9 (VBUS), R605.1, U602.5 (VBUS)
/USB-C programming - board powered/USB_VBUS_SENSE: R605.2, R606.1, U601.8 (VBUS)
GND: C601.2, C602.2, C603.2, C604.2, C605.2, C606.2, C607.2, J601.A1 (GND), J601.A12 (GND), J601.B1 (GND), J601.B12 (GND), R601.2, R602.2, R603.2, R606.2, U601.2 (GND), U601.18 (~CTS), U601.25 (GND), U602.2 (GND); also elsewhere on the board
PROG_RX: U601.20 (RXD); also elsewhere on the board
PROG_TX: JP601.2 (C); also elsewhere on the board
SERVICE_TX: JP601.3 (B); also elsewhere on the board

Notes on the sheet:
USB-C PROGRAMMING / MANUAL BOOT
Board 3.3 V must be powered. USB VBUS is sensed only; it does not feed +5V or +3V3.
JP601: 1-2 USB (default)
2-3 external service UART
Never fit both shunts.
Separate bypass pairs at VREGIN, VDD and VIO.
CP2102N: regulator bypassed; VREGIN/VDD/VIO tied to board 3.3 V.
Configure USB descriptor as self-powered. RTS/DTR unused; use BOOT and RESET.

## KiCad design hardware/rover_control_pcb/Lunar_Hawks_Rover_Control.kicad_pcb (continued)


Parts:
C701: 100nF / 16V; C_0603_1608Metric
C702: 4.7uF / 16V; C_0805_2012Metric
C703: 100nF / 10V; C_0603_1608Metric
D701: NUP2105LT1G; SOT-23
D702: GREEN / CAN ACT; LED_0603_1608Metric
J701: CAN_TO_JETSON; Molex_Micro-Fit_3.0_43650-0300_1x03_P3.00mm_Horizontal
J702: CAN_EXPANSION; Molex_Micro-Fit_3.0_43650-0300_1x03_P3.00mm_Horizontal
JP701: END_TERMINATION; PinHeader_1x02_P2.54mm_Vertical
R701, R702: 10k; R_0603_1608Metric
R703: 120R 1% / 0.25W; R_1206_3216Metric
R704: 1k; R_0603_1608Metric
U701: TCAN1042HGVDRQ1; SOIC-8_3.9x4.9mm_P1.27mm

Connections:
+3V3: C703.1, R701.1, U701.5 (VIO); also elsewhere on the board
+5V: C701.1, C702.1, U701.3 (VCC); also elsewhere on the board
/Classical CAN bus and activity LED/CAN_H: D701.1 (K), J701.1, J702.1, JP701.1 (A), U701.7 (CANH)
/Classical CAN bus and activity LED/CAN_L: D701.2 (K), J701.2, J702.2, R703.2, U701.6 (CANL)
/Classical CAN bus and activity LED/CAN_LED_A: D702.2 (A), R704.2
/Classical CAN bus and activity LED/CAN_STB: R702.1, U701.8 (STB)
/Classical CAN bus and activity LED/CAN_TERM: JP701.2 (B), R703.1
CAN_LED: R704.1; also elsewhere on the board
CAN_RX: U701.4 (RXD); also elsewhere on the board
CAN_TX: R701.2, U701.1 (TXD); also elsewhere on the board
GND: C701.2, C702.2, C703.2, D701.3 (A), D702.1 (K), J701.3, J702.3, R702.2, U701.2 (GND); also elsewhere on the board

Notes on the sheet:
CLASSICAL CAN - ESP32 NODE
500 kbit/s initial target. Two connectors share ONE bus. Terminate only at the two cable ends.
JP701: fit only if this PCB is a bus end.
GPIO32 LED: firmware stretches valid TX/RX events.
Non-isolated node: cable pin 3 is signal reference, never motor-current return.
Jetson J401 still needs a nearby transceiver. CAN_TX/RX must not connect to CAN_H/L.
Cable/ground arrangement and transient performance require system validation.

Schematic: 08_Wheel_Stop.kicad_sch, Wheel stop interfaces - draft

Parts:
J801: WHEEL_1_STOP; PinHeader_1x03_P2.54mm_Vertical
J802: WHEEL_2_STOP; PinHeader_1x03_P2.54mm_Vertical
J803: WHEEL_3_STOP; PinHeader_1x03_P2.54mm_Vertical
J804: WHEEL_4_STOP; PinHeader_1x03_P2.54mm_Vertical
Q801, Q802, Q803, Q804, Q805: AO3400A; SOT-23
R801, R802, R803, R804: 680R 1%; R_0603_1608Metric
R805: 100k; R_0603_1608Metric
R811, R812, R813, R814: 47k 1%; R_0603_1608Metric
R821, R822, R823, R824: 0R DNP; R_0603_1608Metric; not fitted
U801, U802, U803, U804: LTV-817S-B; SMDIP-4_W9.53mm

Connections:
+5V: R801.1, R802.1, R803.1, R804.1; also elsewhere on the board
/Wheel stop interfaces/STOP_RELEASE_K: Q805.3 (D), U801.2, U802.2, U803.2, U804.2
/Wheel stop interfaces/W1_DRIVER_5V: J801.3, R811.1
/Wheel stop interfaces/W1_RELEASE_LED_A: R801.2, U801.1
/Wheel stop interfaces/W1_STOP_CONTACT: J801.2, R821.2
/Wheel stop interfaces/W1_STOP_DRAIN: Q801.3 (D), R821.1
/Wheel stop interfaces/W1_STOP_GATE: Q801.1 (G), R811.2, U801.4
/Wheel stop interfaces/W2_DRIVER_5V: J802.3, R812.1
/Wheel stop interfaces/W2_RELEASE_LED_A: R802.2, U802.1
/Wheel stop interfaces/W2_STOP_CONTACT: J802.2, R822.2
/Wheel stop interfaces/W2_STOP_DRAIN: Q802.3 (D), R822.1
/Wheel stop interfaces/W2_STOP_GATE: Q802.1 (G), R812.2, U802.4
/Wheel stop interfaces/W3_DRIVER_5V: J803.3, R813.1
/Wheel stop interfaces/W3_RELEASE_LED_A: R803.2, U803.1
/Wheel stop interfaces/W3_STOP_CONTACT: J803.2, R823.2
/Wheel stop interfaces/W3_STOP_DRAIN: Q803.3 (D), R823.1
/Wheel stop interfaces/W3_STOP_GATE: Q803.1 (G), R813.2, U803.4
/Wheel stop interfaces/W4_DRIVER_5V: J804.3, R814.1
/Wheel stop interfaces/W4_RELEASE_LED_A: R804.2, U804.1
/Wheel stop interfaces/W4_STOP_CONTACT: J804.2, R824.2
/Wheel stop interfaces/W4_STOP_DRAIN: Q804.3 (D), R824.1
/Wheel stop interfaces/W4_STOP_GATE: Q804.1 (G), R814.2, U804.4
GND: J801.1, J802.1, J803.1, J804.1, Q801.2 (S), Q802.2 (S), Q803.2 (S), Q804.2 (S), Q805.2 (S), R805.2, U801.3, U802.3, U803.3, U804.3; also elsewhere on the board
MOTION_ENABLED: Q805.1 (G), R805.1; also elsewhere on the board

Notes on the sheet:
WHEEL STOP / DRIVER-POWERED DEFAULT STOP REQUEST
Prototype only: populate STOP links after verifying actual ZS-X11H input behavior. This is not the battery-power E-stop.
Four separate driver 5 V inputs: NEVER join them to one another or the PCB 5 V rail. Signal grounds are shared; system is not isolated.
WHEEL 1: NO RELEASE LIGHT -> STOP SWITCH CLOSED
WHEEL 2: NO RELEASE LIGHT -> STOP SWITCH CLOSED
WHEEL 3: NO RELEASE LIGHT -> STOP SWITCH CLOSED
WHEEL 4: NO RELEASE LIGHT -> STOP SWITCH CLOSED
MOTION_ENABLED high lights all four optocouplers (~22 mA total from PCB 5 V) and pulls STOP gates low, opening the STOP switches.
J801-J804: 1 signal GND, 2 driver STOP terminal, 3 that driver's 5 V OUT. Not motor power. No BRAKE connection in this stage.


Board: 4 copper layers, 160.0 x 100.0 mm, 207 parts (1 on the bottom side), 140 nets.

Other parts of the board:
H1, H2, H3, H4: MountingHole_3.2mm_M3
LOGO1: UHCL_Lunar_Hawks_Logo
LOGO2: UHCL_Front_Logo_23mm

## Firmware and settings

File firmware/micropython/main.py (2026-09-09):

import time
from machine import Pin, PWM
from microdot import Microdot
from microdot.websocket import with_websocket

# ==================================================
# PIN DEFINITIONS (same as Arduino)
# ==================================================

DIR_FR = Pin(2, Pin.OUT)
DIR_FL = Pin(4, Pin.OUT)
DIR_BR = Pin(5, Pin.OUT)
DIR_BL = Pin(13, Pin.OUT)

FR_PWM = PWM(Pin(18), freq=20000)
BR_PWM = PWM(Pin(19), freq=20000)
FL_PWM = PWM(Pin(32), freq=20000)
BL_PWM = PWM(Pin(33), freq=20000)

MOTOR_IN1 = Pin(25, Pin.OUT)
MOTOR_IN2 = Pin(26, Pin.OUT)

servoPin = Pin(12, Pin.OUT)
signalPin = Pin(23, Pin.OUT)

# ==================================================
# SAFE STARTUP
# ==================================================
def all_stop():
    FR_PWM.duty(0)
    BR_PWM.duty(0)
    FL_PWM.duty(0)
    BL_PWM.duty(0)

    DIR_FR.value(0)
    DIR_FL.value(0)
    DIR_BR.value(0)
    DIR_BL.value(0)

    MOTOR_IN1.value(0)
    MOTOR_IN2.value(0)
    servoPin.value(0)
    signalPin.value(0)

all_stop()
print("SAFE STARTUP: Motors OFF")

# ==================================================
# MOTOR CONTROL HELPERS
# ==================================================
def set_pwm(pwm, val):
    duty = min(max(int(val), 0), 255)
    pwm.duty(duty)

# ==================================================
# FORWARD / BACKWARD (unchanged)
# ==================================================
def forward(power):
    set_pwm(FR_PWM, power * 1.2)
    set_pwm(BR_PWM, power)
    set_pwm(FL_PWM, power * 1.8)
    set_pwm(BL_PWM, power)

    DIR_FR.value(1)
    DIR_FL.value(1)
    DIR_BR.value(0)
    DIR_BL.value(0)

def backward(power):
    set_pwm(FR_PWM, power * 1.8)
    set_pwm(BR_PWM, power * 1.5)
    set_pwm(FL_PWM, power / 1.2)
    set_pwm(BL_PWM, power / 1.5)

    DIR_FR.value(0)
    DIR_FL.value(0)
    DIR_BR.value(1)
    DIR_BL.value(1)

# ==================================================
# UPDATED TANK TURNING (NEW)
# ==================================================
def tankLeft(power):
    print("TANK LEFT")

    # RIGHT wheels forward
    set_pwm(FR_PWM, power)
    set_pwm(BR_PWM, power)
    DIR_FR.value(1)
    DIR_BR.value(1)

    # LEFT wheels reverse
    set_pwm(FL_PWM, power)
    set_pwm(BL_PWM, power)
    DIR_FL.value(1)
    DIR_BL.value(1)

def tankRight(power):
    print("TANK RIGHT")

    # LEFT wheels forward
    set_pwm(FL_PWM, power)
    set_pwm(BL_PWM, power)
    DIR_FL.value(0)
    DIR_BL.value(0)

    # RIGHT wheels reverse
    set_pwm(FR_PWM, power)
    set_pwm(BR_PWM, power)
    DIR_FR.value(0)
    DIR_BR.value(0)

# ==================================================
# OLD ARC TURNING (no longer used, but kept)
# ==================================================
def leftforward(power):
    set_pwm(FR_PWM, power)
    set_pwm(BR_PWM, power)
    set_pwm(FL_PWM, 0)
    set_pwm(BL_PWM, 0)

    DIR_FR.value(1)
    DIR_FL.value(1)
    DIR_BR.value(0)
    DIR_BL.value(0)

def rightforward(power):
    set_pwm(FR_PWM, 0)
    set_pwm(BR_PWM, 0)
    set_pwm(FL_PWM, power * 1.5)
    set_pwm(BL_PWM, power * 1.5)

    DIR_FR.value(1)
    DIR_FL.value(1)
    DIR_BR.value(0)
    DIR_BL.value(0)

# ==================================================
# GENERAL CONTROL
# ==================================================
def stop():
    all_stop()

def up():
    MOTOR_IN1.value(1)
    MOTOR_IN2.value(0)

def down():
    MOTOR_IN1.value(0)
    MOTOR_IN2.value(1)

def dump():
    servoPin.value(1)

# ==================================================
# WEBSOCKET SERVER
# ==================================================

POWER = 40

app = Microdot()

@app.route("/")
def index(req):
    return "ESP32 Rover Ready"

@app.route("/ws")
@with_websocket
async def ws_handler(req, ws):
    print("WS connected")

    while True:
        msg = await ws.receive()
        if msg is None:
            break

        msg = msg.strip()
        print("RX:", msg)

        # Driving
        if msg == "FWD":
            forward(POWER)
        elif msg == "BACK":
            backward(POWER)
        elif msg == "LEFT":
            tankLeft(POWER)        # *** NEW TANK LEFT ***
        elif msg == "RIGHT":
            tankRight(POWER)       # *** NEW TANK RIGHT ***
        elif msg == "STOP":
            stop()

        # Actuator
        elif msg == "RB":
            up()
        elif msg == "LB":
            down()

        # Dump
        elif msg == "triangle":
            dump()

        # Extra signal pin
        elif msg == "X":
            signalPin.value(1)

        await ws.send("ACK")

    all_stop()
    print("WS disconnected")

print("Microdot running on 0.0.0.0:81")
app.run(host="0.0.0.0", port=81)

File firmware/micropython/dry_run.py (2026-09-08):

"""Limited WebSocket dry-run server for CPython/MicroPython; NO GPIO outputs.

Single client, <=125-byte masked, unfragmented text messages. No TLS/auth.
Bind to localhost for host tests; private lab network only on an ESP32.
Do not turn this into a physical controller without a separate safety design.
"""
import asyncio
import binascii
import hashlib
import json
import math
import sys
import time

GUID = b"258EAFA5-E914-47DA-95CA-C5AB0DC85B11"
TIMEOUT_MS = 500


def now_ms():
    if hasattr(time, "ticks_ms"):
        return time.ticks_ms()
    return int(time.monotonic() * 1000)


def elapsed_ms(now, then):
    if hasattr(time, "ticks_diff"):
        return time.ticks_diff(now, then)
    return now - then


def parse_command(payload):
    """Require explicit deadman and finite normalized v/w values."""
    obj = json.loads(payload)
    if not isinstance(obj, dict) or set(obj) != {"v", "w", "deadman"}:
        raise ValueError("Expected only v, w and deadman")
    if type(obj["deadman"]) is not bool:
        raise ValueError("deadman must be boolean")
    for name in ("v", "w"):
        value = obj[name]
        if type(value) not in (int, float):
            raise ValueError("v and w must be numbers, not booleans")
        if not math.isfinite(value) or not -1.0 <= value <= 1.0:
            raise ValueError("v and w must be finite and within [-1, 1]")
    if not obj["deadman"]:
        return 0.0, 0.0
    return float(obj["v"]), float(obj["w"])


def mix(v, w):
    """Normalized arcade mixer, NOT calibrated velocity or PWM units."""
    left, right = v - w, v + w
    scale = max(1.0, abs(left), abs(right))
    return left / scale, right / scale


class DryRunController:
    """Records normalized left/right requests only; cannot drive hardware."""

    def __init__(self):
        self.outputs = (0.0, 0.0)
        self.last_ms = None

    def stop(self):
        self.outputs = (0.0, 0.0)
        self.last_ms = None

    def receive(self, payload, stamp):
        try:
            self.outputs = mix(*parse_command(payload))
            self.last_ms = stamp
        except (ValueError, TypeError, OverflowError):
            self.stop()
            raise
        return self.outputs

    def expire(self, stamp):
        if self.last_ms is not None:
            if elapsed_ms(stamp, self.last_ms) >= TIMEOUT_MS:
                self.stop()
        return self.outputs


def accept_key(key):
    raw = binascii.a2b_base64(key)
    if len(raw) != 16:
        raise ValueError("Invalid WebSocket key")
    return binascii.b2a_base64(hashlib.sha1(key + GUID).digest()).strip()


async def handshake(reader, writer):
    """Bound the full HTTP header to 2048 bytes; caller bounds duration."""
    header = bytearray()
    while not header.endswith(b"\r\n\r\n"):
        if len(header) >= 2048:
            raise ValueError("Header too large")
        header.extend(await reader.readexactly(1))
    lines = bytes(header).split(b"\r\n")
    if lines[0] != b"GET /control HTTP/1.1":
        raise ValueError("Use /control")
    fields = {}
    for line in lines[1:]:
        if line:
            name, value = line.split(b":", 1)
            name = name.strip().lower()
            if name in fields:
                raise ValueError("Duplicate header")
            fields[name] = value.strip()
    connection = [s.strip().lower() for s in fields.get(b"connection", b"").split(b",")]
    if (fields.get(b"upgrade", b"").lower() != b"websocket"
            or b"upgrade" not in connection
            or fields.get(b"sec-websocket-version") != b"13"):
        raise ValueError("Invalid upgrade")
    key = accept_key(fields.get(b"sec-websocket-key", b""))
    writer.write(b"HTTP/1.1 101 Switching Protocols\r\n"
                 b"Upgrade: websocket\r\nConnection: Upgrade\r\n"
                 b"Sec-WebSocket-Accept: " + key + b"\r\n\r\n")
    await writer.drain()


async def read_frame(reader):
    """Deliberately supports only short FIN frames, without extensions."""
    first, second = await reader.readexactly(2)
    opcode, length = first & 15, second & 127
    if not first & 128 or first & 112 or not second & 128:
        raise ValueError("Requires FIN, no extensions, and masking")
    if opcode not in (1, 8, 9, 10) or length > 125:
        raise ValueError("Unsupported frame")
    mask = await reader.readexactly(4)
    data = await reader.readexactly(length)
    return opcode, bytes(x ^ mask[i % 4] for i, x in enumerate(data))


class DryRunServer:
    """A second connection cannot take ownership or stop an active client."""

    def __init__(self):
        self.controller = DryRunController()
        self.busy = False

    async def handle(self, reader, writer):
        if self.busy:
            writer.close()
            await writer.wait_closed()
            return
        self.busy = True
        try:
            await asyncio.wait_for(handshake(reader, writer), 2.0)
            while True:
                # Short timeout includes the whole frame, not each byte.
                opcode, payload = await asyncio.wait_for(read_frame(reader), 0.5)
                if opcode == 8:
                    writer.write(b"\x88\x00")
                    await writer.drain()
                    break
                if opcode == 9:
                    writer.write(bytes((138, len(payload))) + payload)
                    await writer.drain()
                elif opcode == 1:
                    result = self.controller.receive(payload.decode("utf-8"), now_ms())
                    reply = json.dumps({"dry_run": True, "left": result[0],
                                        "right": result[1]}).encode()
                    writer.write(bytes((129, len(reply))) + reply)
                    await writer.drain()
        except (Exception,):
            # Any malformed input, disconnect or timeout clears dry-run state.
            pass
        finally:
            self.controller.stop()
            writer.close()
            try:
                await writer.wait_closed()
            finally:
                self.busy = False

    async def watchdog(self):
        while True:
            self.controller.expire(now_ms())
            await asyncio.sleep(0.02)


async def serve(host="127.0.0.1", port=8765):
    service = DryRunServer()
    watchdog = asyncio.create_task(service.watchdog())
    server = await asyncio.start_server(service.handle, host, port)
    print("DRY RUN WebSocket on", host, port, "/control")
    try:
        while True:
            await asyncio.sleep(1)
    finally:
        watchdog.cancel()
        server.close()
        await server.wait_closed()
        service.controller.stop()


if __name__ == "__main__":
    if sys.implementation.name == "micropython":
        print("Dry-run main.py loaded. Start serve() explicitly at the REPL.")
    else:
        asyncio.run(serve())

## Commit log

2026-09-08 Organize Lunar Hawks rover sources, add MicroPython main.py and document PCB/research status
    [12_inch+Linear+actuator.stl, 12mm+Sprocket.stl, Bucket+#1.stl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]
2026-09-08 Add Lunabotics autonomy, Gazebo simulation, CAD, and electrical updates
    [goal_post.scad, goal_post.stl, grouser_wheel_12_short.scad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]
2026-09-09 Add reference-derived full rover CAD and experimental Gazebo integration
    [Lunar_Hawks_RevC.kicad_sch, bucket.stl, chassis.stl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]
2026-09-09 Correct top-hinged latch door and four-actuator excavation sequence
    [Lunar_Hawks_RevC.kicad_sch, actuator_body.stl, actuator_rod.stl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]
2026-09-09 Add actual Gazebo RViz runtime and KiCad ERC validation jobs
2026-09-09 Fix KiCad ERC grid, symbol library and sensor interface errors
    [Lunar_Hawks_RevC.kicad_sch]
2026-09-09 Fix camera namespace found by Gazebo runtime validation
    [lunar_hawks.urdf]
2026-09-09 Use free-hinge dynamics for passive door and diagnose simulation poses
    [lunar_hawks.urdf]
2026-09-09 Preserve passive door velocity during kinematic bucket updates
2026-09-09 Record passing Gazebo RViz and KiCad validation with runtime screenshots
2026-09-09 Replace full-rover wheels with photo-derived open spokes and twelve swept fins
    [lunar_hawks.urdf, rover.scad, wheel.stl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]
2026-09-09 Reinforce wheel and resize to 248 mm for 256 mm print bed
    [lunar_hawks.urdf, rover.scad, wheel.stl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]
2026-09-09 Add swept thin-tip grousers and removable wheel cavity covers
    [lunar_hawks.urdf, rover.scad, wheel.stl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]
2026-09-09 Distinguish close returns, invalid scans and timeouts in LiDAR stop diagnostics
2026-09-09 Gate mission startup on stable simulation clock and clear camera from LiDAR plane
    [lunar_hawks.urdf]
2026-09-09 Implement Wi-Fi connection and safety pin initialization
    Added Wi-Fi connection setup and safety measures for motor pins.
2026-09-09 Add 300 mm laboratory wheel test article
    [wheel_300mm_lab.scad, wheel_300mm_lab.stl]
2026-09-09 Add preview for 300 mm laboratory wheel
2026-09-09 Replace lab wheel with verified binary STL
    [wheel_300mm_lab.stl]
2026-09-09 Add covered lab wheel and printable side cover
    [wheel_300mm_lab.scad, wheel_300mm_lab_cover.stl, wheel_300mm_lab_covered.stl]
2026-09-09 Add printable body for covered 300 mm wheel
    [wheel_300mm_lab_body_for_covers.stl]
2026-09-09 Prevent simulated LiDAR self-returns
    [lunar_hawks.urdf]
2026-09-09 Confirm near LiDAR returns across consecutive scans
2026-09-09 Restore organized CAD directory structure
    [actuator_body.stl, actuator_rod.stl, bucket.stl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]
2026-09-09 Hold on transient LiDAR stops before latching mission fault
2026-09-09 Place simulated LiDAR above rover self-occlusion
    [lunar_hawks.urdf]
2026-09-13 Start Rev A KiCad rover control schematic architecture
2026-09-13 Add Rev A top-level rover control KiCad architecture
    [rover_control_revA.kicad_sch]
2026-09-13 Add Rev A power protection schematic sheet
    [01_power_protection.kicad_sch]
2026-09-13 Add Rev A MCU and Jetson communications sheet
    [02_mcu_comms.kicad_sch]
2026-09-13 Add Rev A hardware safety and E-stop sheet
    [03_safety_estop.kicad_sch]
2026-09-13 Add Rev A external driver output sheet
    [04_driver_outputs.kicad_sch]
2026-09-13 Add Rev A sensor and feedback interface sheet
    [05_sensors_feedback.kicad_sch]
2026-09-13 Document Rev A rover power-stage connectivity
2026-09-13 Add Rev A candidate power-stage BOM
    [power_revA.csv]
2026-09-13 Implement Rev A power-stage candidate circuit
    [01_power_protection.kicad_sch]
2026-09-14 Update Rev A rover control PCB documentation and status
2026-09-14 Add Flux PCB images and design exports
2026-09-14 Fix PCB render link and design-file index
2026-09-14 Add PCB STEP export notes
2026-09-14 Update schematic docs for current ESP32-WROOM Flux design
2026-09-14 Document current Rev A PCB placement and routing state
2026-09-14 Update preliminary BOM for current Rev A design
2026-09-14 Update PCB requirements for ESP32-WROOM and required CAN architecture
2026-09-14 Update rover PCB interface specification
2026-09-14 Add preliminary Rev A JLCPCB BOM export
    [rover_control_safety_revA_JLCPCB.csv]
2026-09-14 Update Rev A PCB design review checklist
2026-09-14 Change PCB image format in README
    Updated image format from .webp to .png in README.
2026-09-14 Update README with PCB layout and power-plane review
    Added PCB layout and power-plane review section with image.
2026-09-14 Update BOM description for clarity
2026-09-14 Remove PCB layout and power-plane review details
2026-09-16 Refocus rover PCB documentation on KiCad 9.0
2026-09-16 Rewrite PCB layout notes for KiCad 9.0
2026-09-16 Stage KiCad PCB import workflow
2026-09-16 Replace preliminary BOM with current KiCad 9.0 BOM
2026-09-16 Remove obsolete PCB design export
2026-09-16 Remove obsolete schematic design export
2026-09-16 Remove superseded BOM export
    [power_revA.csv]
2026-09-16 Point BOM documentation to current KiCad BOM
2026-09-16 Rewrite schematic documentation for KiCad 9.0
2026-09-16 Remove temporary PCB import workflow
2026-09-16 Replace incomplete rover PCB upload with checked KiCad draft and logos
    [01_Power.kicad_sch, 01_power_protection.kicad_sch, 02_MCU_Comms.kicad_sch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]
2026-09-16 Create schematics
2026-09-16 Organize KiCad rover control PCB project and update renders
    [PCB_Placement.csv]
2026-09-24 Clarify PCB design status and project documentation
